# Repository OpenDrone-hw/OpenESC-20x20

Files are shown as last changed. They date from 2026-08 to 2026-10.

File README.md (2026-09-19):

# OpenESC-20x20

Open source 4-in-1 BLDC ESC with a 20 x 20 mm mounting pattern, part of the
incutec OpenDrone line. Four independent motor controllers, each with its own
MCU, gate driver and six MOSFETs, running AM32 and taking DShot over the
standard 8-pin connector.

<p>
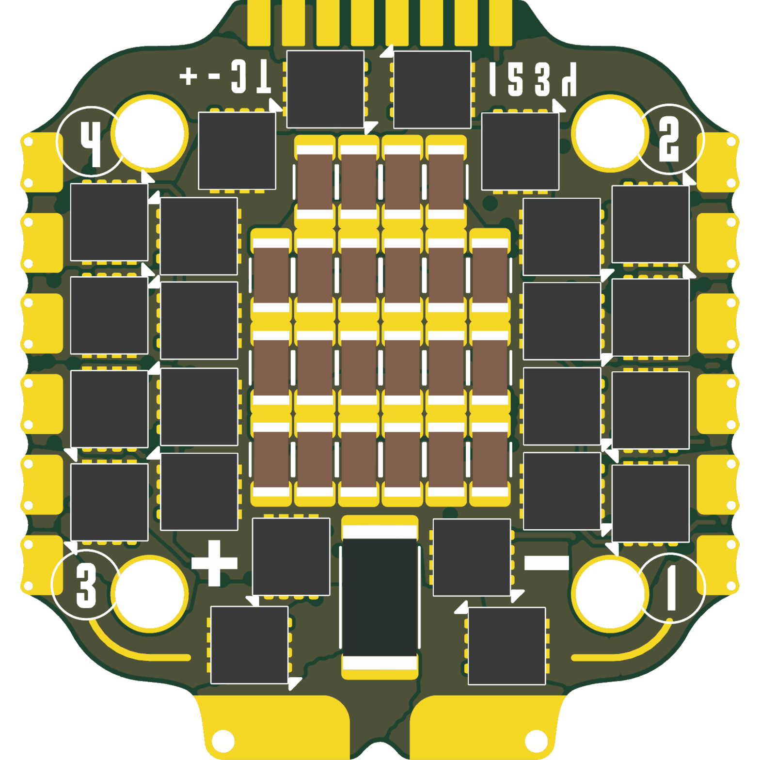
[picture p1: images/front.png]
OpenESC-20x20 top

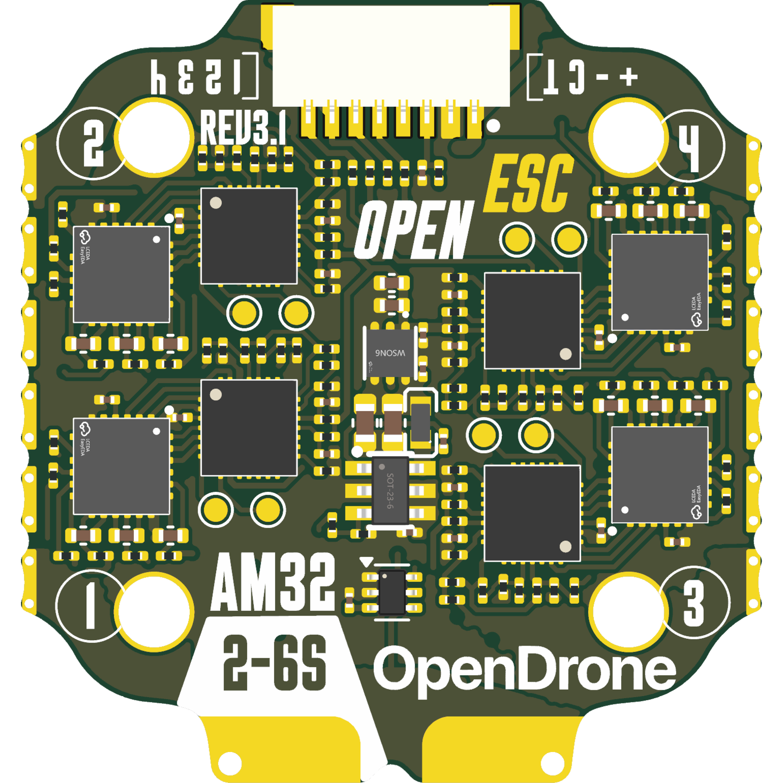
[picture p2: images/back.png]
OpenESC-20x20 bottom

</p>







## Specifications

| | |
|---|---|
| Continuous | 40 A / channel |
| Firmware | AM32 |
| ESC protocol | DShot, bidirectional |
| Telemetry | Extended DShot |
| Input | 2-6S LiPo (6.0-25.2 V) |
| BEC | None |
| MCU | One per motor |
| MOSFETs | 6 per motor |
| Current sense | On-board, 165 A |
| FC connector | JST-SH 8-pin |
| Mounting | 20 x 20 mm, 3.0 mm holes |
| Dimensions | 31.2 x 33.0 mm |
| PCB | 6-layer, 1.6 mm, 2 oz copper |

Technical write-up, part list and layout constraints: [AGENTS.md](AGENTS.md).

## In the line

What pairs with what, and what is available:
[opendrone.be](https://opendrone.be).

## Contributing

See [CONTRIBUTING.md](CONTRIBUTING.md).

## License

Hardware licensed under [CERN-OHL-S-2.0](https://ohwr.org/cern_ohl_s_v2.txt),
see [LICENSE](LICENSE).

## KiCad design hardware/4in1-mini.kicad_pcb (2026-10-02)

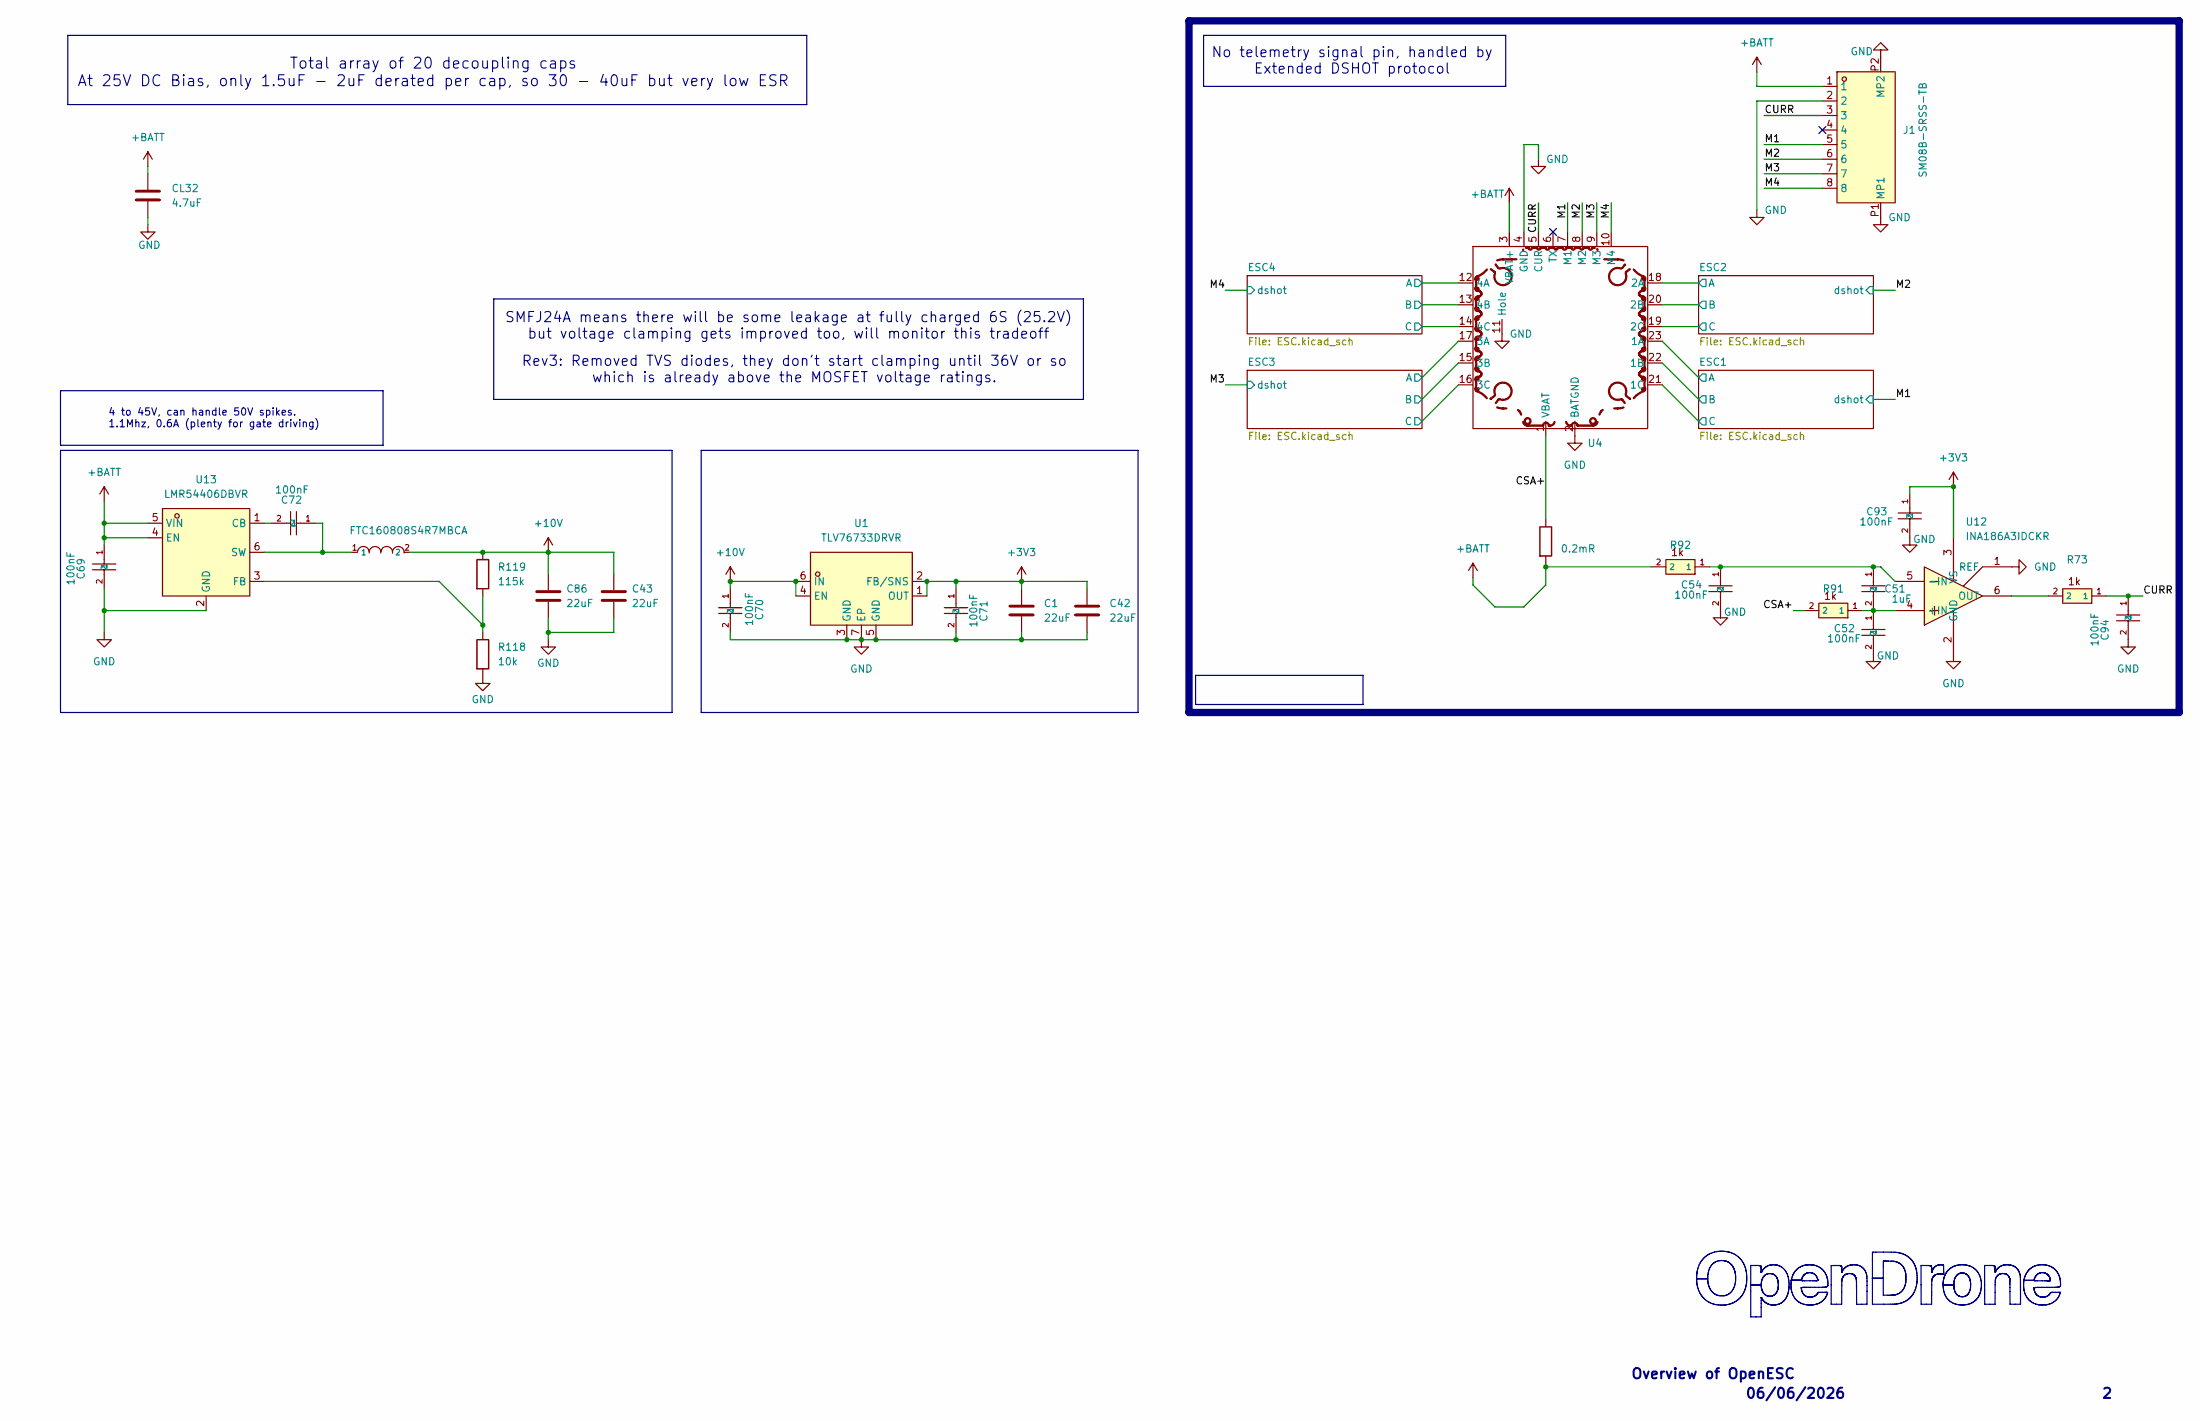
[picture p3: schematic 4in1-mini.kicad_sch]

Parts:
C1, C42: 22uF; C_0402_1005Metric; MPN CL05A226MQ5QUNC; LCSC C105226
C43, C86: 22uF; C_0603_1608Metric; MPN CL10A226MO7JZNC; LCSC C2762594
C51: 1uF; C_0402_1005Metric; MPN CC0402KRX7R6BB105; LCSC C7500381
C52, C54: 100nF; C_0402_WIDE; MPN CL05B104KB54PNC; LCSC C307331
C69, C70, C71, C72, C93, C94: 100nF; C_0201_0603Metric; MPN GRM033R6YA104KE14D; LCSC C181043
CL32: 4.7uF; C_1206_3216Metric; MPN TCC1206X7R475K500HT; LCSC C380366
J1: SM08B-SRSS-TB; JST_SM08B-SRSS-TB; MPN SM08B-SRSS-TB(LF)(SN); LCSC C160407
R73: 1k; R_0201_0603Metric; MPN 0201WMF1001TEE; LCSC C270365
R91, R92: 1k; C_0201_0603Metric; MPN 0201WMF1001TEE; LCSC C270365
R118: 10k; R_0201_0603Metric; MPN RC0201FR-0710KL; LCSC C106225
R119: 115k; R_0201_0603Metric; MPN RTT011153FTH; LCSC C166378
Rsense2: 0.2mR; R_2512_6332Metric; MPN ASR-S-3-0.2F; LCSC C695806
U1: TLV76733DRVR; WSON-6_L2.0-W2.0-P0.65-TL-EP; MPN TLV76733DRVR; LCSC C2848334
U4: 4in1ESC
U5: FTC160808S4R7MBCA; IND-SMD_L1.6-W0.8_FTC160865SR47MBCA; MPN FTC160808S4R7MBCA; LCSC C46594347
U12: INA186A3IDCKR; SOT-363_SC-70-6; MPN INA186A3IDCKR; LCSC C2058245
U13: LMR54406DBVR; SOT-23-6_L2.9-W1.6-P0.95-LS2.8-BR; MPN LMR54406DBVR; LCSC C5219316

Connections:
+3V3: C1.2, C42.2, C71.1, C93.1, U1.1 (OUT), U1.2 (FB/SNS), U12.3 (VS); also elsewhere on the board
+10V: C43.1, C70.1, C86.1, R119.1, U1.4 (EN), U1.6 (IN), U5.2; also elsewhere on the board
+BATT: C69.1, CL32.1, J1.1, R92.2, Rsense2.2, U4.3 (VBAT+), U13.4 (EN), U13.5 (VIN); also elsewhere on the board
/CSA+: R91.2, Rsense2.1, U4.1 (VBAT)
/CURR: C94.1, J1.3, R73.1, U4.5 (CUR)
/ESC1/MotorA: U4.23 (1A); also elsewhere on the board
/ESC1/MotorB: U4.22 (1B); also elsewhere on the board
/ESC1/MotorC: U4.21 (1C); also elsewhere on the board
/ESC2/MotorA: U4.18 (2A); also elsewhere on the board
/ESC2/MotorB: U4.20 (2B); also elsewhere on the board
/ESC2/MotorC: U4.19 (2C); also elsewhere on the board
/ESC3/MotorA: U4.17 (3A); also elsewhere on the board
/ESC3/MotorB: U4.15 (3B); also elsewhere on the board
/ESC3/MotorC: U4.16 (3C); also elsewhere on the board
/ESC4/MotorA: U4.12 (4A); also elsewhere on the board
/ESC4/MotorB: U4.13 (4B); also elsewhere on the board
/ESC4/MotorC: U4.14 (4C); also elsewhere on the board
/M1: J1.5, U4.7 (M1); also elsewhere on the board
/M2: J1.6, U4.8 (M2); also elsewhere on the board
/M3: J1.7, U4.9 (M3); also elsewhere on the board
/M4: J1.8, U4.10 (M4); also elsewhere on the board
GND: C1.1, C42.1, C43.2, C52.2, C54.2, C69.2, C70.2, C71.2, C86.2, C93.2, C94.2, CL32.2, J1.2, J1.P1 (MP1), J1.P2 (MP2), R118.2, U1.3 (GND), U1.5 (GND), U1.7 (EP), U4.2 (BATGND), U4.4 (GND), U4.11 (Hole), U12.1 (REF), U12.2 (GND), U13.2 (GND); also elsewhere on the board
unnamed: C51.2, C52.1, R91.1, U12.4 (+IN)
unnamed: C51.1, C54.1, R92.1, U12.5 (-IN)
unnamed: R73.2, U12.6 (OUT)
unnamed: C72.2, U13.1 (CB)
unnamed: R118.1, R119.2, U13.3 (FB)
unnamed: C72.1, U5.1, U13.6 (SW)

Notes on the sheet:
06/06/2026
No telemetry signal pin, handled by Extended DSHOT protocol
4 to 45V, can handle 50V spikes. 1.1Mhz, 0.6A (plenty for gate driving)
Rev3: Removed TVS diodes, they don't start clamping until 36V or so which is already above the MOSFET voltage ratings.
SMFJ24A means there will be some leakage at fully charged 6S (25.2V) but voltage clamping gets improved too, will monitor this tradeoff
Overview of OpenESC
Total array of 20 decoupling caps At 25V DC Bias, only 1.5uF - 2uF derated per cap, so 30 - 40uF but very low ESR

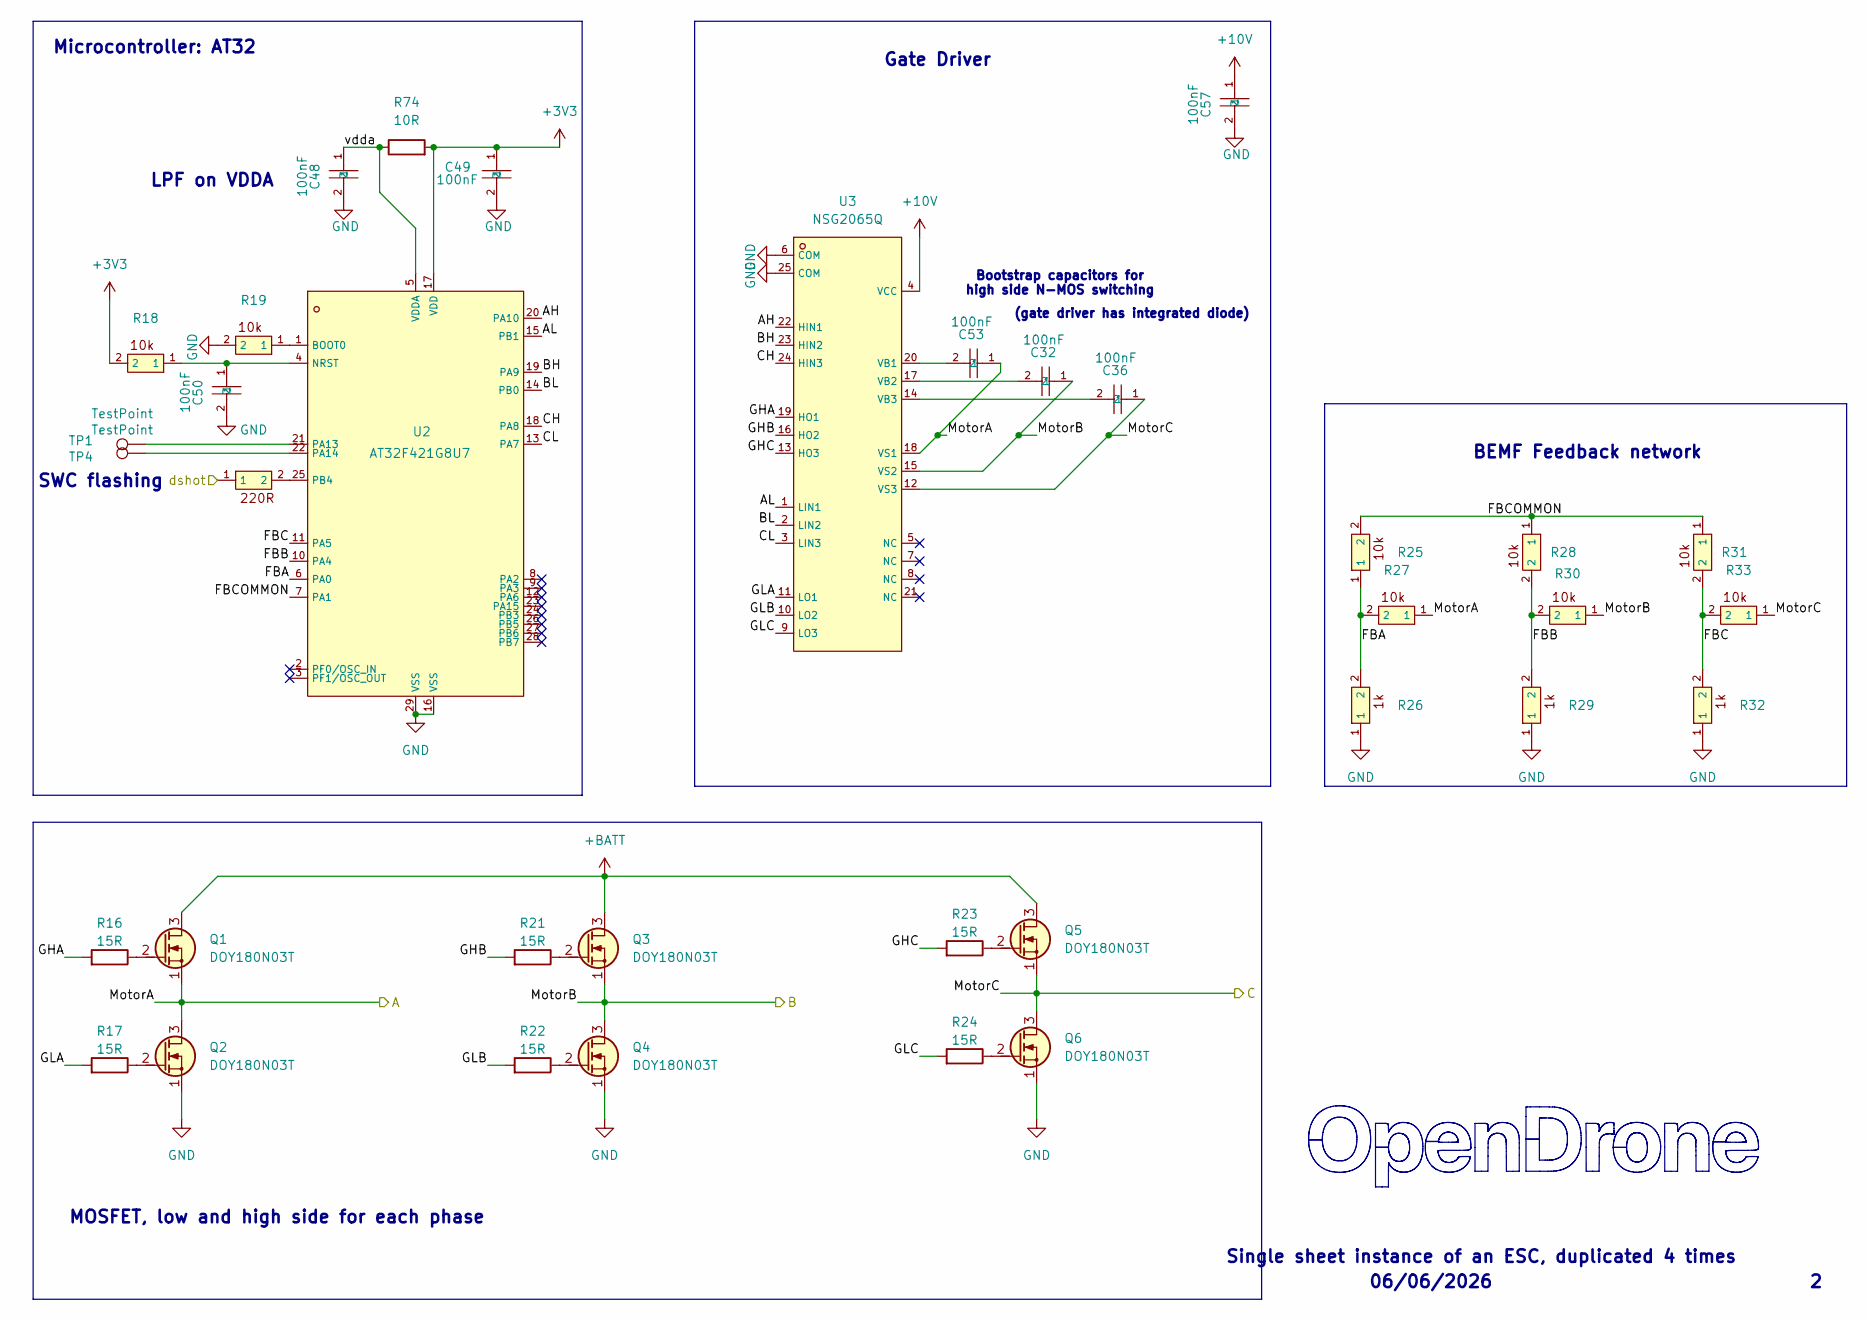
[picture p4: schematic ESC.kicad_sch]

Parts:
C32, C36, C53: 100nF; C_0402_WIDE; MPN CL05B104KB54PNC; LCSC C307331
C48, C49, C50, C57: 100nF; C_0201_0603Metric; MPN GRM033R6YA104KE14D; LCSC C181043
Q1, Q2, Q3, Q4, Q5, Q6: DOY180N03T; Diodes_PowerDI3333-8; MPN DOY180N03T; LCSC C49441966
R16, R17, R21, R22, R23, R24: 15R; R_0201_0603Metric; MPN 0201WMF150JTEE; LCSC C473542
R18, R19, R25, R27, R28, R30, R31, R33: 10k; R_0201_0603Metric; MPN RC0201FR-0710KL; LCSC C106225
R20: 220R; R_0201_0603Metric; MPN AC0201FR-07220RL; LCSC C226468
R26, R29, R32: 1k; R_0201_0603Metric; MPN 0201WMF1001TEE; LCSC C270365
R74: 10R; R_0201_0603Metric; MPN RC0201FR-0710RL; LCSC C106226
TP1, TP4: TestPoint; TestPoint_Pad_D1.0mm
U2: AT32F421G8U7; QFN-28_L4.0-W4.0-P0.40-TL-EP2.4; MPN AT32F421G8U7; LCSC C2765098
U3: NSG2065Q; QFN-24_L4.0-W4.0-P0.50-TL-EP2.8; MPN NSG2065Q; LCSC C41414478

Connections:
+3V3: C49.1, R18.2, R74.2, U2.17 (VDD); also elsewhere on the board
+10V: C57.1, U3.4 (VCC); also elsewhere on the board
+BATT: Q1.3 (D), Q3.3 (D), Q5.3 (D); also elsewhere on the board
/ESC1/AH: U2.20 (PA10), U3.22 (HIN1)
/ESC1/AL: U2.15 (PB1), U3.1 (LIN1)
/ESC1/BH: U2.19 (PA9), U3.23 (HIN2)
/ESC1/BL: U2.14 (PB0), U3.2 (LIN2)
/ESC1/CH: U2.18 (PA8), U3.24 (HIN3)
/ESC1/CL: U2.13 (PA7), U3.3 (LIN3)
/ESC1/FBA: R25.1, R26.2, R27.2, U2.6 (PA0)
/ESC1/FBB: R28.2, R29.2, R30.2, U2.10 (PA4)
/ESC1/FBC: R31.2, R32.2, R33.2, U2.11 (PA5)
/ESC1/FBCOMMON: R25.2, R28.1, R31.1, U2.7 (PA1)
/ESC1/GHA: R16.1, U3.19 (HO1)
/ESC1/GHB: R21.1, U3.16 (HO2)
/ESC1/GHC: R23.1, U3.13 (HO3)
/ESC1/GLA: R17.1, U3.11 (LO1)
/ESC1/GLB: R22.1, U3.10 (LO2)
/ESC1/GLC: R24.1, U3.9 (LO3)
/ESC1/MotorA: C53.1, Q1.1 (S), Q2.3 (D), R27.1, U3.18 (VS1); also elsewhere on the board
/ESC1/MotorB: C32.1, Q3.1 (S), Q4.3 (D), R30.1, U3.15 (VS2); also elsewhere on the board
/ESC1/MotorC: C36.1, Q5.1 (S), Q6.3 (D), R33.1, U3.12 (VS3); also elsewhere on the board
/ESC1/vdda: C48.1, R74.1, U2.5 (VDDA)
/M1: R20.1; also elsewhere on the board
GND: C48.2, C49.2, C50.2, C57.2, Q2.1 (S), Q4.1 (S), Q6.1 (S), R19.2, R26.1, R29.1, R32.1, U2.16 (VSS), U2.29 (VSS), U3.6 (COM), U3.25 (COM); also elsewhere on the board
unnamed: Q1.2 (G), R16.2
unnamed: Q2.2 (G), R17.2
unnamed: Q3.2 (G), R21.2
unnamed: Q4.2 (G), R22.2
unnamed: Q5.2 (G), R23.2
unnamed: Q6.2 (G), R24.2
unnamed: R19.1, U2.1 (BOOT0)
unnamed: C50.1, R18.1, U2.4 (NRST)
unnamed: TP1.1 (1_1), U2.21 (PA13)
unnamed: TP4.1 (1_1), U2.22 (PA14)
unnamed: R20.2, U2.25 (PB4)
unnamed: C53.2, U3.20 (VB1)
unnamed: C32.2, U3.17 (VB2)
unnamed: C36.2, U3.14 (VB3)

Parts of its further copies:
C33, C34, C35, C37, C38, C39, C59, C73, C83: 100nF; C_0402_WIDE; MPN CL05B104KB54PNC; LCSC C307331
C44, C45, C46, C63, C64, C65, C66, C77, C78, C79, C80, C88: 100nF; C_0201_0603Metric; MPN GRM033R6YA104KE14D; LCSC C181043
Q7, Q8, Q9, Q10, Q11, Q12, Q13, Q14, Q15, Q16, Q17, Q18, Q19, Q20, Q21, Q22, Q23, Q24: DOY180N03T; Diodes_PowerDI3333-8; MPN DOY180N03T; LCSC C49441966
R1, R2, R6, R7, R8, R9, R37, R38, R42, R43, R44, R45, R55, R56, R60, R61, R62, R63: 15R; R_0201_0603Metric; MPN 0201WMF150JTEE; LCSC C473542
R3, R4, R10, R12, R13, R15, R34, R36, R39, R40, R46, R48, R49, R51, R52, R54, R57, R58, R64, R66, R67, R69, R70, R72: 10k; R_0201_0603Metric; MPN RC0201FR-0710KL; LCSC C106225
R5, R41, R59: 220R; R_0201_0603Metric; MPN AC0201FR-07220RL; LCSC C226468
R11, R14, R35, R47, R50, R53, R65, R68, R71: 1k; R_0201_0603Metric; MPN 0201WMF1001TEE; LCSC C270365
R75, R76, R77: 10R; R_0201_0603Metric; MPN RC0201FR-0710RL; LCSC C106226
TP2, TP3, TP5, TP6, TP7, TP8: TestPoint; TestPoint_Pad_D1.0mm
U6, U8, U10: AT32F421G8U7; QFN-28_L4.0-W4.0-P0.40-TL-EP2.4; MPN AT32F421G8U7; LCSC C2765098
U7, U9, U11: NSG2065Q; QFN-24_L4.0-W4.0-P0.50-TL-EP2.8; MPN NSG2065Q; LCSC C41414478

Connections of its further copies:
+3V3: C45.1, C65.1, C79.1, R3.2, R39.2, R57.2, R75.2, R76.2, R77.2, U6.17 (VDD), U8.17 (VDD), U10.17 (VDD); also elsewhere on the board
+10V: C63.1, C77.1, C88.1, U7.4 (VCC), U9.4 (VCC), U11.4 (VCC); also elsewhere on the board
+BATT: Q7.3 (D), Q9.3 (D), Q11.3 (D), Q13.3 (D), Q15.3 (D), Q17.3 (D), Q19.3 (D), Q21.3 (D), Q23.3 (D); also elsewhere on the board
/ESC2/AH: U6.20 (PA10), U7.22 (HIN1)
/ESC2/AL: U6.15 (PB1), U7.1 (LIN1)
/ESC2/BH: U6.19 (PA9), U7.23 (HIN2)
/ESC2/BL: U6.14 (PB0), U7.2 (LIN2)
/ESC2/CH: U6.18 (PA8), U7.24 (HIN3)
/ESC2/CL: U6.13 (PA7), U7.3 (LIN3)
/ESC2/FBA: R10.1, R11.2, R12.2, U6.6 (PA0)
/ESC2/FBB: R13.2, R14.2, R15.2, U6.10 (PA4)
/ESC2/FBC: R34.2, R35.2, R36.2, U6.11 (PA5)
/ESC2/FBCOMMON: R10.2, R13.1, R34.1, U6.7 (PA1)
/ESC2/GHA: R1.1, U7.19 (HO1)
/ESC2/GHB: R6.1, U7.16 (HO2)
/ESC2/GHC: R8.1, U7.13 (HO3)
/ESC2/GLA: R2.1, U7.11 (LO1)
/ESC2/GLB: R7.1, U7.10 (LO2)
/ESC2/GLC: R9.1, U7.9 (LO3)
/ESC2/MotorA: C59.1, Q7.1 (S), Q8.3 (D), R12.1, U7.18 (VS1); also elsewhere on the board
/ESC2/MotorB: C33.1, Q9.1 (S), Q10.3 (D), R15.1, U7.15 (VS2); also elsewhere on the board
/ESC2/MotorC: C37.1, Q11.1 (S), Q12.3 (D), R36.1, U7.12 (VS3); also elsewhere on the board
/ESC2/vdda: C44.1, R75.1, U6.5 (VDDA)
/ESC3/AH: U8.20 (PA10), U9.22 (HIN1)
/ESC3/AL: U8.15 (PB1), U9.1 (LIN1)
/ESC3/BH: U8.19 (PA9), U9.23 (HIN2)
/ESC3/BL: U8.14 (PB0), U9.2 (LIN2)
/ESC3/CH: U8.18 (PA8), U9.24 (HIN3)
/ESC3/CL: U8.13 (PA7), U9.3 (LIN3)
/ESC3/FBA: R46.1, R47.2, R48.2, U8.6 (PA0)
/ESC3/FBB: R49.2, R50.2, R51.2, U8.10 (PA4)
/ESC3/FBC: R52.2, R53.2, R54.2, U8.11 (PA5)
/ESC3/FBCOMMON: R46.2, R49.1, R52.1, U8.7 (PA1)
/ESC3/GHA: R37.1, U9.19 (HO1)
/ESC3/GHB: R42.1, U9.16 (HO2)
/ESC3/GHC: R44.1, U9.13 (HO3)
/ESC3/GLA: R38.1, U9.11 (LO1)
/ESC3/GLB: R43.1, U9.10 (LO2)
/ESC3/GLC: R45.1, U9.9 (LO3)
/ESC3/MotorA: C73.1, Q13.1 (S), Q14.3 (D), R48.1, U9.18 (VS1); also elsewhere on the board
/ESC3/MotorB: C34.1, Q15.1 (S), Q16.3 (D), R51.1, U9.15 (VS2); also elsewhere on the board
/ESC3/MotorC: C38.1, Q17.1 (S), Q18.3 (D), R54.1, U9.12 (VS3); also elsewhere on the board
/ESC3/vdda: C64.1, R76.1, U8.5 (VDDA)
/ESC4/AH: U10.20 (PA10), U11.22 (HIN1)
/ESC4/AL: U10.15 (PB1), U11.1 (LIN1)
/ESC4/BH: U10.19 (PA9), U11.23 (HIN2)
/ESC4/BL: U10.14 (PB0), U11.2 (LIN2)
/ESC4/CH: U10.18 (PA8), U11.24 (HIN3)
/ESC4/CL: U10.13 (PA7), U11.3 (LIN3)
/ESC4/FBA: R64.1, R65.2, R66.2, U10.6 (PA0)
/ESC4/FBB: R67.2, R68.2, R69.2, U10.10 (PA4)
/ESC4/FBC: R70.2, R71.2, R72.2, U10.11 (PA5)
/ESC4/FBCOMMON: R64.2, R67.1, R70.1, U10.7 (PA1)
/ESC4/GHA: R55.1, U11.19 (HO1)
/ESC4/GHB: R60.1, U11.16 (HO2)
/ESC4/GHC: R62.1, U11.13 (HO3)
/ESC4/GLA: R56.1, U11.11 (LO1)
/ESC4/GLB: R61.1, U11.10 (LO2)
/ESC4/GLC: R63.1, U11.9 (LO3)
/ESC4/MotorA: C83.1, Q19.1 (S), Q20.3 (D), R66.1, U11.18 (VS1); also elsewhere on the board
/ESC4/MotorB: C35.1, Q21.1 (S), Q22.3 (D), R69.1, U11.15 (VS2); also elsewhere on the board
/ESC4/MotorC: C39.1, Q23.1 (S), Q24.3 (D), R72.1, U11.12 (VS3); also elsewhere on the board
/ESC4/vdda: C78.1, R77.1, U10.5 (VDDA)
/M2: R5.1; also elsewhere on the board
/M3: R41.1; also elsewhere on the board
/M4: R59.1; also elsewhere on the board
GND: C44.2, C45.2, C46.2, C63.2, C64.2, C65.2, C66.2, C77.2, C78.2, C79.2, C80.2, C88.2, Q8.1 (S), Q10.1 (S), Q12.1 (S), Q14.1 (S), Q16.1 (S), Q18.1 (S), Q20.1 (S), Q22.1 (S), Q24.1 (S), R4.2, R11.1, R14.1, R35.1, R40.2, R47.1, R50.1, R53.1, R58.2, R65.1, R68.1, R71.1, U6.16 (VSS), U6.29 (VSS), U7.6 (COM), U7.25 (COM), U8.16 (VSS), U8.29 (VSS), U9.6 (COM), U9.25 (COM), U10.16 (VSS), U10.29 (VSS), U11.6 (COM), U11.25 (COM); also elsewhere on the board
unnamed: Q7.2 (G), R1.2
unnamed: Q8.2 (G), R2.2
unnamed: Q9.2 (G), R6.2
unnamed: Q10.2 (G), R7.2
unnamed: Q11.2 (G), R8.2
unnamed: Q12.2 (G), R9.2
unnamed: Q13.2 (G), R37.2
unnamed: Q14.2 (G), R38.2
unnamed: Q15.2 (G), R42.2
unnamed: Q16.2 (G), R43.2
unnamed: Q17.2 (G), R44.2
unnamed: Q18.2 (G), R45.2
unnamed: Q19.2 (G), R55.2
unnamed: Q20.2 (G), R56.2
unnamed: Q21.2 (G), R60.2
unnamed: Q22.2 (G), R61.2
unnamed: Q23.2 (G), R62.2
unnamed: Q24.2 (G), R63.2
unnamed: R4.1, U6.1 (BOOT0)
unnamed: C46.1, R3.1, U6.4 (NRST)
unnamed: TP2.1 (1_1), U6.21 (PA13)
unnamed: TP3.1 (1_1), U6.22 (PA14)
unnamed: R5.2, U6.25 (PB4)
unnamed: C59.2, U7.20 (VB1)
unnamed: C33.2, U7.17 (VB2)
unnamed: C37.2, U7.14 (VB3)
unnamed: R40.1, U8.1 (BOOT0)
unnamed: C66.1, R39.1, U8.4 (NRST)
unnamed: TP5.1 (1_1), U8.21 (PA13)
unnamed: TP6.1 (1_1), U8.22 (PA14)
unnamed: R41.2, U8.25 (PB4)
unnamed: C73.2, U9.20 (VB1)
unnamed: C34.2, U9.17 (VB2)
unnamed: C38.2, U9.14 (VB3)
unnamed: R58.1, U10.1 (BOOT0)
unnamed: C80.1, R57.1, U10.4 (NRST)
unnamed: TP7.1 (1_1), U10.21 (PA13)
unnamed: TP8.1 (1_1), U10.22 (PA14)
unnamed: R59.2, U10.25 (PB4)
unnamed: C83.2, U11.20 (VB1)
unnamed: C35.2, U11.17 (VB2)
unnamed: C39.2, U11.14 (VB3)

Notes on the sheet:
Bootstrap capacitors for high side N-MOS switching
Gate Driver
MOSFET, low and high side for each phase
Single sheet instance of an ESC, duplicated 4 times
Microcontroller: AT32
SWC flashing
(gate driver has integrated diode)
06/06/2026
BEMF Feedback network
LPF on VDDA

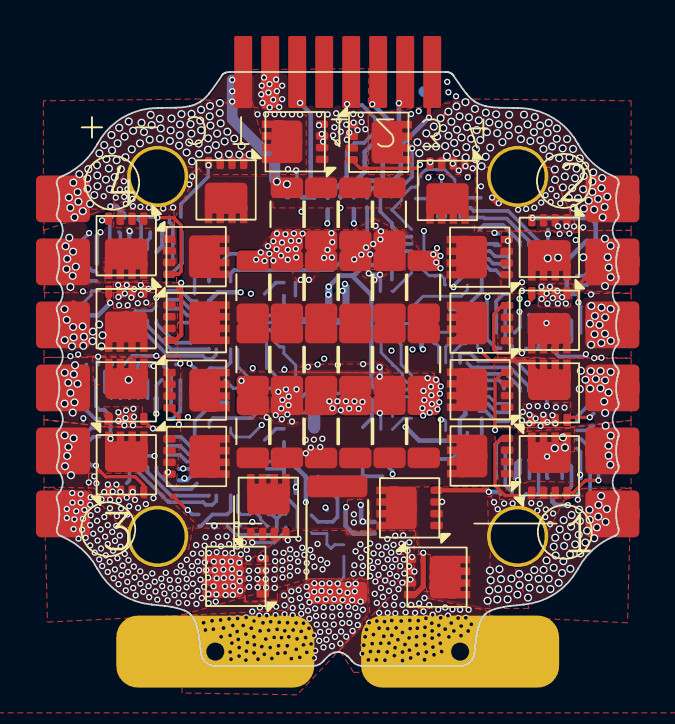
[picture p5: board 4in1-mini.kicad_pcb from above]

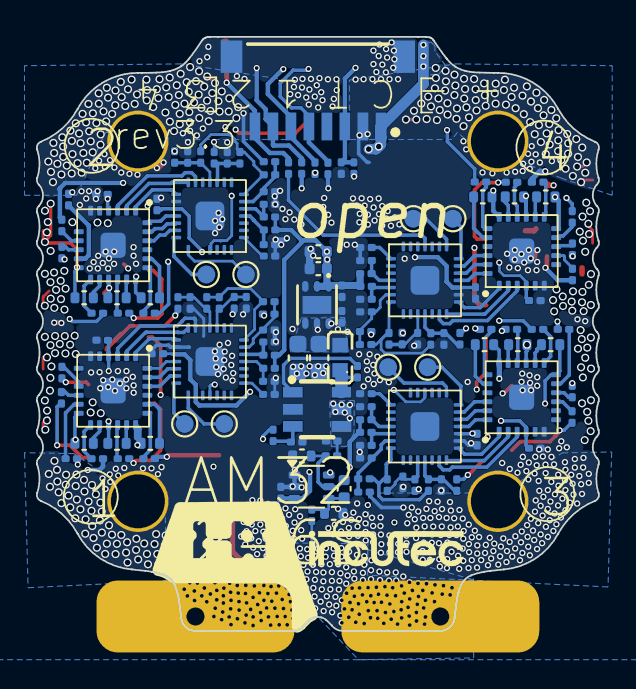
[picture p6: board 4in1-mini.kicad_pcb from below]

Board: 6 copper layers, 31.2 x 33.0 mm, 191 parts (143 on the bottom side), 152 nets.

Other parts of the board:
CL33, CL34, CL35, CL36, CL38, CL39, CL40, CL42, CL43, CL44, CL45, CL46, CL47, CL48, CL49, CL50, CL50#2, CL51, CL51#2, CL54, CL55: 4.7uF; C_1206_3216Metric

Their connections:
+BATT: CL33.1, CL34.1, CL35.1, CL36.1, CL38.1, CL39.1, CL40.1, CL42.1, CL43.1, CL44.1, CL45.1, CL46.1, CL47.1, CL48.1, CL49.1, CL50.1, CL50#2.1, CL51.1, CL51#2.1, CL54.1, CL55.1; also elsewhere on the board
GND: CL33.2, CL34.2, CL35.2, CL36.2, CL38.2, CL39.2, CL40.2, CL42.2, CL43.2, CL44.2, CL45.2, CL46.2, CL47.2, CL48.2, CL49.2, CL50.2, CL50#2.2, CL51.2, CL51#2.2, CL54.2, CL55.2; also elsewhere on the board

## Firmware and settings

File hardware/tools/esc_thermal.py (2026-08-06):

#!/usr/bin/env python3
"""
4in1 ESC Power Loss & Thermal Calculator

Models AM32 trapezoidal 6-step commutation with steady-state and transient thermal.

MOSFET profiles:
  20x20: SP40N03GNJ (Siliup Ver-1.2), Rg=15Ω. SUPERSEDED POWER STAGE. The
         shipping OpenESC-20x20 uses 24x DOY180N03T (30 V, PowerDI3333-8, LCSC
         C49441966, see hardware/docs/DESIGN.md). This profile has not been
         re-parameterized from the DOY180N03T datasheet, so its loss and
         temperature numbers do not describe the current board. Board geometry
         (1030 mm², 6 layers) is current.
  30x30: SP40N01GHNK (Siliup Ver-1.1), Rg=8Ω. Matches the OpenESC-30x30 board.
  Gate driver for both: NSG2065Q (NSIC V1.0).
"""

import argparse
import math

# ═══════════════════════════════════════════════════════════════
#  MOSFET profiles: all values from datasheets
# ═══════════════════════════════════════════════════════════════

PROFILES = {
    "20x20": {
        "name":         "20×20  SP40N03GNJ (3×3mm, SUPERSEDED, not the shipping part)",
        # ── SP40N03GNJ datasheet (Ver-1.2) ──
        "rds_on":       2.9e-3,     # Ω typ @ Vgs=10V, ID=20A, 25°C
        "rds_on_max":   3.7e-3,     # Ω max
        "rds_tempco":   1.45,       # normalized @ 100°C (p3 curve)
        "rds_tempco_150": 1.70,     # normalized @ 150°C
        "qg_at_10v":    15e-9,      # C  (from gate charge curve p3 @ Vgs=10V)
        "qgd":          5.5e-9,     # C  gate-drain (Miller) charge
        "vgs":          10.0,       # V
        "rg":           15.0,       # Ω  external gate resistor
        "v_plateau":    3.0,        # V  Miller plateau (transfer curve p3)
        # Switching: Qgd / I_gate through Rg
        #   I_on  = (10-3)/15 = 0.47A → tr = 5.5nC/0.47A = 11.7ns
        #   I_off = 3/15      = 0.20A → tf = 5.5nC/0.20A = 27.5ns
        "tr":           11.7e-9,
        "tf":           27.5e-9,
        "vf_body_cold": 0.80,       # V  @ ~30A, 25°C (p4 curve extrapolated)
        "vf_body_hot":  0.65,       # V  @ ~30A, 100°C
        "trr":          14e-9,      # s  (p2)
        "qrr":          23e-9,      # C  (p2)
        "rth_jc":       2.27,       # °C/W (p2)
        "pd_max":       55.0,       # W
        "tj_max":       150.0,      # °C
        # Board
        "board_mm":     20,         # mm mounting pattern
        "board_area":   1030.0,     # mm² actual PCB (~31×33mm, from Edge.Cuts)
        "r_copper":     3.2e-3,     # Ω per phase trace
        "r_shunt":      0.2e-3,     # Ω
        "layers":       6,
        "oz_outer":     1,          # oz copper
        "oz_inner":     0.5,
    },
    "30x30": {
        "name":         "30×30  SP40N01GHNK (5×6mm)",
        # ── SP40N01GHNK datasheet (Ver-1.1) ──
        "rds_on":       1.2e-3,     # Ω typ @ Vgs=10V, ID=20A, 25°C
        "rds_on_max":   1.5e-3,     # Ω max
        "rds_tempco":   1.45,       # normalized @ 100°C (p3 curve)
        "rds_tempco_150": 1.70,     # normalized @ 150°C
        "qg_at_10v":    65e-9,      # C  (from gate charge curve p3 @ Vgs=10V)
        "qgd":          15.5e-9,    # C  gate-drain (Miller) charge
        "vgs":          10.0,       # V
        "rg":           8.0,        # Ω  external gate resistor
        "v_plateau":    3.5,        # V  Miller plateau (transfer curve p3, higher Vth)
        # Switching: Qgd / I_gate through Rg
        #   I_on  = (10-3.5)/8 = 0.81A → tr = 15.5nC/0.81A = 19.1ns
        #   I_off = 3.5/8      = 0.44A → tf = 15.5nC/0.44A = 35.2ns
        "tr":           19.1e-9,
        "tf":           35.2e-9,
        "vf_body_cold": 0.75,       # V  @ ~30A, 25°C (p3 source-drain diode curve)
        "vf_body_hot":  0.60,       # V  @ ~30A, 100°C
        "trr":          29e-9,      # s  (p2)
        "qrr":          113e-9,     # C  (p2), much higher than SP40N03GNJ
        "rth_jc":       0.96,       # °C/W (p2), better, larger package
        "pd_max":       130.0,      # W
        "tj_max":       150.0,      # °C
        # Board
        "board_mm":     30,         # mm mounting pattern
        "board_area":   1770.0,     # mm² actual PCB (~42×43mm, from Edge.Cuts)
        "r_copper":     2.0e-3,     # Ω per phase (wider traces, more area)
        "r_shunt":      0.2e-3,     # Ω
        "layers":       6,
        "oz_outer":     1,
        "oz_inner":     0.5,
    },
}

# ─── NSG2065Q gate driver (shared) ───
GATE_DRIVER = {
    "dead_time_typ":  200e-9,   # s  hardware dead time (100-300ns, p6)
    "dead_time_min":  100e-9,
    "dead_time_max":  300e-9,
    "io_source":      1.2,      # A
    "io_sink":        1.5,      # A
}

# ─── Thermal scenarios ───
# h = convective heat transfer coefficient (W/m²·K)
# θ_board = 1 / (h × A_both_sides)
THERMAL_SCENARIOS = {
    "still":        {"h": 15,   "label": "Still air (bench)"},
    "light_flow":   {"h": 50,   "label": "Light prop wash (~3m/s)"},
    "strong_flow":  {"h": 100,  "label": "Strong prop wash (~8m/s)"},
    "direct_blast": {"h": 150,  "label": "Direct motor blast (>10m/s)"},
}

# ─── PCB stackup options for thermal comparison ───
# Copper thickness: 1oz=35µm, 2oz=70µm, 0.5oz=17.5µm
# Thermal conductivity: Cu=385 W/(m·K), FR4=0.3 W/(m·K)
PCB_OPTIONS = {
    "jlcpcb_6L_1oz": {
        "label":    "JLCPCB 6L 1oz/0.5oz (current)",
        "oz_outer": 1.0, "oz_inner": 0.5, "layers": 6,
        "notes":    "Standard, free POFV via-in-pad",
    },
    "jlcpcb_6L_2oz": {
        "label":    "JLCPCB 6L 2oz/2oz (max multilayer)",
        "oz_outer": 2.0, "oz_inner": 2.0, "layers": 6,
        "notes":    "Max Cu at JLCPCB for 6L, ~2x bare board cost",
    },
    "jlcpcb_4L_2oz": {
        "label":    "JLCPCB 4L 2oz/2oz",
        "oz_outer": 2.0, "oz_inner": 2.0, "layers": 4,
        "notes":    "Cheaper than 6L, no free POFV",
    },
    "jlcpcb_6L_3oz": {
        "label":    "JLCPCB 6L 3oz/1oz (industry std ESC)",
        "oz_outer": 3.0, "oz_inner": 1.0, "layers": 6,
        "notes":    "What commercial 35A ESCs use",
    },
    "pcbway_6L_4oz": {
        "label":    "PCBWay 6L 4oz/2oz (heavy Cu)",
        "oz_outer": 4.0, "oz_inner": 2.0, "layers": 6,
        "notes":    "PCBWay supports >2oz on multilayer, premium cost",
    },
}


def board_theta(area_mm2: float, h: float) -> float:
    """Board-to-ambient thermal resistance (°C/W), both sides convecting."""
    area_m2 = area_mm2 * 2.0 * 1e-6
    return 1.0 / (h * area_m2)


def board_thermal_mass(area_mm2: float, layers: int, oz_outer: float, oz_inner: float,
                       board_thickness_mm: float = 1.6) -> float:
    """Board thermal capacitance in J/K.

    Accounts for FR-4 substrate and copper layers.
    FR-4: ρ=1.85 g/cm³, cp=1.1 J/(g·K)
    Cu:   ρ=8.96 g/cm³, cp=0.385 J/(g·K)
    """
    area_cm2 = area_mm2 * 1e-2  # mm² → cm²

    # FR-4 volume (approximate: total thickness minus copper)
    cu_outer_mm = oz_outer * 0.035  # mm per oz
    cu_inner_mm = oz_inner * 0.035 if oz_inner else 0.0175
    n_inner = max(layers - 2, 0)
    total_cu_mm = 2 * cu_outer_mm + n_inner * cu_inner_mm
    fr4_mm = board_thickness_mm - total_cu_mm
    fr4_vol_cm3 = area_cm2 * fr4_mm * 0.1  # cm²×mm→cm³ needs ×0.1
    fr4_mass = fr4_vol_cm3 * 1.85
    fr4_cth = fr4_mass * 1.1

    # Copper volume
    cu_vol_cm3 = area_cm2 * total_cu_mm * 0.1
    cu_mass = cu_vol_cm3 * 8.96
    cu_cth = cu_mass * 0.385

    return fr4_cth + cu_cth


def copper_resistance_scaled(r_base: float, oz_base: float, oz_new: float) -> float:
    """Scale copper trace resistance for different copper weight.
    R ∝ 1/thickness, so doubling oz halves resistance.
    """
    return r_base * oz_base / oz_new


def calc_phase_losses(i: float, v_bus: float, duty: float, f_pwm: float,
                      comp_pwm: bool, dead_time: float, p: dict,
                      r_copper_override: float = None) -> dict:
    """Calculate losses for one active phase pair."""
    rds = p["rds_on"] * p["rds_tempco"]  # hot Rds(on)
    vf = p["vf_body_hot"]
    r_cu = r_copper_override if r_copper_override else p["r_copper"]

    # Conduction
    p_cond_hs = i**2 * rds * duty
    if comp_pwm:
        p_cond_ls = i**2 * rds * (1.0 - duty)
        p_body = 0.0
    else:
        p_cond_ls = 0.0
        p_body = vf * i * (1.0 - duty)
    p_cond_low = i**2 * rds  # LOW-phase FET, 100% on

    # Switching (Miller plateau crossing)
    p_switch = 0.5 * v_bus * i * (p["tr"] + p["tf"]) * f_pwm

    # Dead time (both edges per PWM cycle)
    p_dead = vf * i * dead_time * 2.0 * f_pwm

    # Reverse recovery (Qrr-based model)
    p_rr = p["qrr"] * v_bus * f_pwm

    # Gate drive (HS at f_pwm, LS at commutation freq ~200Hz)
    p_gate = p["qg_at_10v"] * p["vgs"] * f_pwm + p["qg_at_10v"] * p["vgs"] * 200

    # Copper (both phase traces in the current path)
    p_copper = i**2 * r_cu * 2.0

    # Shunt
    p_shunt = i**2 * p["r_shunt"]

    p_fet = p_cond_hs + p_cond_ls + p_body + p_cond_low + p_switch + p_dead + p_rr + p_gate
    p_passive = p_copper + p_shunt
    p_total = p_fet + p_passive

    return {
        "p_cond_hs": p_cond_hs, "p_cond_ls": p_cond_ls, "p_body": p_body,
        "p_cond_low": p_cond_low, "p_switch": p_switch, "p_dead": p_dead,
        "p_rr": p_rr, "p_gate": p_gate, "p_copper": p_copper, "p_shunt": p_shunt,
        "p_fet": p_fet, "p_passive": p_passive, "p_total": p_total,
    }


def transient_time_to_tj(p_board: float, theta_ba: float, c_th: float,
                         tj_max: float, t_ambient: float) -> float:
    """Time (seconds) from ambient to Tj_max under constant power.

    Simple first-order RC model: ΔT(t) = ΔT_ss × (1 - e^(-t/τ))
    τ = C_th × θ_ba
    Returns float('inf') if steady-state ΔT < (Tj_max - T_ambient).
    """
    dt_max = tj_max - t_ambient
    dt_ss = p_board * theta_ba
    if dt_ss <= dt_max:
        return float('inf')  # never reaches Tj_max
    tau = c_th * theta_ba
    return -tau * math.log(1.0 - dt_max / dt_ss)


def print_full_report(profile_key: str, i: float, v_bus: float, duty: float,
                      f_pwm: float, comp_pwm: bool, dead_time: float, n_active: int):
    p = PROFILES[profile_key]
    rds_hot = p["rds_on"] * p["rds_tempco"]
    losses = calc_phase_losses(i, v_bus, duty, f_pwm, comp_pwm, dead_time, p)

    p_board = losses["p_total"] * n_active
    p_motor = v_bus * i * duty * n_active
    eff = p_motor / (p_motor + p_board) * 100 if p_motor > 0 else 0

    print("=" * 70)
    print(f"  4in1 ESC Power Loss Report  -  {p['name']}")
    print(f"  AM32 6-Step Trapezoidal  |  NSG2065Q gate driver")
    print("=" * 70)
    print(f"  Battery voltage:      {v_bus:.1f} V")
    print(f"  Phase current:        {i:.1f} A")
    print(f"  Duty cycle:           {duty*100:.1f}%")
    print(f"  PWM frequency:        {f_pwm/1e3:.0f} kHz")
    print(f"  Dead time:            {dead_time*1e9:.0f} ns  (NSG2065Q HW)")
    print(f"  Comp PWM:             {'ON' if comp_pwm else 'OFF'}")
    print(f"  Gate resistor:        {p['rg']:.0f}Ω  →  tr={p['tr']*1e9:.1f}ns  tf={p['tf']*1e9:.1f}ns")
    print(f"  Rds(on):              {p['rds_on']*1e3:.1f}mΩ cold → {rds_hot*1e3:.1f}mΩ hot (×{p['rds_tempco']})")
    print(f"  Active phases:        {n_active}")
    print("-" * 70)

    print(f"\n  Per phase pair (HS + LS MOSFET + copper):")
    print(f"    HS conduction:     {losses['p_cond_hs']:7.3f} W  (I²×Rds×D)")
    if comp_pwm:
        print(f"    LS sync rect:      {losses['p_cond_ls']:7.3f} W  (I²×Rds×(1-D))")
    else:
        print(f"    Body diode:        {losses['p_body']:7.3f} W  (Vf×I×(1-D))")
    print(f"    LOW-phase FET:     {losses['p_cond_low']:7.3f} W  (I²×Rds, 100%)")
    print(f"    Switching:         {losses['p_switch']:7.3f} W")
    print(f"    Dead time:         {losses['p_dead']:7.3f} W")
    print(f"    Reverse recovery:  {losses['p_rr']:7.3f} W  (Qrr={p['qrr']*1e9:.0f}nC)")
    print(f"    Gate drive:        {losses['p_gate']:7.3f} W")
    print(f"    ────────────────────────────────────────")
    print(f"    FET subtotal:      {losses['p_fet']:7.3f} W")
    print(f"    Copper (×2):       {losses['p_copper']:7.3f} W  ({p['r_copper']*1e3:.1f}mΩ/phase)")
    print(f"    Shunt:             {losses['p_shunt']:7.3f} W")
    print(f"    ────────────────────────────────────────")
    print(f"    Phase total:       {losses['p_total']:7.3f} W")

    print(f"\n  Board totals ({n_active} phases):")
    print(f"    Heat dissipation:  {p_board:7.2f} W")
    print(f"    Motor output:      {p_motor:7.1f} W")
    print(f"    Efficiency:        {eff:7.1f}%")

    # ─── Steady-state thermal ───
    area = p["board_area"]
    c_th = board_thermal_mass(area, p["layers"], p["oz_outer"], p["oz_inner"])

    print(f"\n  Steady-state thermal ({area:.0f}mm² board, {p['layers']}L "
          f"{p['oz_outer']:.0f}oz/{p['oz_inner']}oz):")
    print(f"  {'Scenario':<28s} {'θ':>6s}  {'ΔT':>6s}  {'Tj@25°C':>7s}  {'Tj@40°C':>7s}")
    print(f"  {'-'*62}")

    for key, sc in THERMAL_SCENARIOS.items():
        theta = board_theta(area, sc["h"])
        dt = p_board * theta
        tj25 = 25 + dt
        tj40 = 40 + dt
        w = " !! EXCEED" if tj25 > 150 else " ! HOT" if tj25 > 125 else ""
        print(f"  {sc['label']:<28s} {theta:5.1f}°/W  +{dt:4.0f}°C  {tj25:6.0f}°C  {tj40:6.0f}°C{w}")

    # ─── Transient thermal ───
    print(f"\n  Transient thermal (time to Tj=150°C from 25°C ambient):")
    print(f"  Board thermal mass: {c_th:.2f} J/K")
    print(f"  {'Scenario':<28s} {'τ':>6s}  {'t to 150°C':>10s}")
    print(f"  {'-'*50}")

    for key, sc in THERMAL_SCENARIOS.items():
        theta = board_theta(area, sc["h"])
        tau = c_th * theta
        t_max = transient_time_to_tj(p_board, theta, c_th, 150, 25)
        if t_max == float('inf'):
            t_str = "never"
        elif t_max < 1:
            t_str = f"{t_max*1000:.0f} ms"
        else:
            t_str = f"{t_max:.1f} s"
        print(f"  {sc['label']:<28s} {tau:5.1f}s   {t_str:>10s}")

    # ─── MOSFET limits ───
    p_worst_fet = max(
        losses["p_cond_hs"] + losses["p_switch"] + losses["p_dead"]/2 + losses["p_rr"],
        losses["p_cond_low"] + losses["p_body"] + losses["p_dead"]/2,
    )
    print(f"\n  MOSFET: RθJC={p['rth_jc']:.2f}°C/W  Pd_max={p['pd_max']:.0f}W  Tj_max={p['tj_max']:.0f}°C")
    print(f"  Worst single FET: {p_worst_fet:.2f}W → ΔTjc={p_worst_fet*p['rth_jc']:.1f}°C above pad")
    print("=" * 70)


def sweep(profile_key: str, currents: list, v_bus: float, duty: float,
          f_pwm: float, comp_pwm: bool, dead_time: float, n_active: int):
    p = PROFILES[profile_key]
    area = p["board_area"]
    c_th = board_thermal_mass(area, p["layers"], p["oz_outer"], p["oz_inner"])
    theta_fly = board_theta(area, 100)  # strong prop wash

    print()
    print(f"  {p['name']}  @  {v_bus:.0f}V  {duty*100:.0f}%  {f_pwm/1e3:.0f}kHz  "
          f"comp_pwm={'ON' if comp_pwm else 'OFF'}")
    print(f"  Board: {area:.0f}mm²  θ_propwash={theta_fly:.1f}°/W  C_th={c_th:.2f}J/K")
    print(f"  {'I':>6s}  {'Phase':>7s}  {'Board':>7s}  {'Eff':>5s}  "
          f"{'Tj_fly':>6s}  {'t→150°C':>8s}  {'Rating':>12s}")
    print(f"  {'-'*66}")

    for current in currents:
        losses = calc_phase_losses(current, v_bus, duty, f_pwm, comp_pwm, dead_time, p)
        p_board = losses["p_total"] * n_active
        p_motor = v_bus * current * duty * n_active
        eff = p_motor / (p_motor + p_board) * 100 if p_motor > 0 else 0
        tj_fly = 25 + p_board * theta_fly
        t_max = transient_time_to_tj(p_board, theta_fly, c_th, 150, 25)

        if t_max == float('inf'):
            t_str = "∞"
            if tj_fly < 100:
                rating = "continuous"
            elif tj_fly < 125:
                rating = "continuous*"
            else:
                rating = "marginal"
        elif t_max > 10:
            t_str = f"{t_max:.0f}s"
            rating = "burst OK"
        elif t_max > 3:
            t_str = f"{t_max:.1f}s"
            rating = "burst limit"
        else:
            t_str = f"{t_max:.1f}s"
            rating = "DANGER"

        print(f"  {current:5.0f}A  {losses['p_total']:6.2f}W  {p_board:6.1f}W  "
              f"{eff:4.1f}%  {tj_fly:5.0f}°C  {t_str:>8s}  {rating:>12s}")

    print()
    print("  continuous  = Tj < 100°C steady-state in prop wash")
    print("  continuous* = Tj 100-125°C (hot but survivable)")
    print("  marginal    = Tj 125-150°C (near limit)")
    print("  burst OK    = >10s to Tj_max (typical punch-out)")
    print("  burst limit = 3-10s to Tj_max")
    print()


def compare_boards(v_bus: float, duty: float, f_pwm: float, comp_pwm: bool,
                   dead_time: float, n_active: int):
    """Side-by-side comparison of both ESC variants."""
    currents = [5, 10, 15, 20, 25, 30, 35, 40, 50]

    print()
    print("=" * 78)
    print("  BOARD COMPARISON  -  20×20 vs 30×30")
    print(f"  {v_bus:.0f}V  {duty*100:.0f}% duty  {f_pwm/1e3:.0f}kHz  "
          f"comp_pwm={'ON' if comp_pwm else 'OFF'}  {n_active} phases")
    print("=" * 78)

    for key in ["20x20", "30x30"]:
        p = PROFILES[key]
        area = p["board_area"]
        c_th = board_thermal_mass(area, p["layers"], p["oz_outer"], p["oz_inner"])
        theta_fly = board_theta(area, 100)
        rds_hot = p["rds_on"] * p["rds_tempco"]

        print(f"\n  {p['name']}")
        print(f"  Rds(on)={rds_hot*1e3:.1f}mΩ hot  Rg={p['rg']:.0f}Ω  "
              f"Qrr={p['qrr']*1e9:.0f}nC  RθJC={p['rth_jc']:.2f}°/W")
        print(f"  θ_fly={theta_fly:.1f}°/W  C_th={c_th:.2f}J/K  "
              f"R_cu={p['r_copper']*1e3:.1f}mΩ/phase")
        print(f"  {'I':>6s}  {'Board W':>7s}  {'Eff':>5s}  "
              f"{'Tj_fly':>6s}  {'t→150°C':>8s}")
        print(f"  {'-'*44}")

        for current in currents:
            losses = calc_phase_losses(current, v_bus, duty, f_pwm, comp_pwm, dead_time, p)
            p_board = losses["p_total"] * n_active
            p_motor = v_bus * current * duty * n_active
            eff = p_motor / (p_motor + p_board) * 100 if p_motor > 0 else 0
            tj_fly = 25 + p_board * theta_fly
            t_max = transient_time_to_tj(p_board, theta_fly, c_th, 150, 25)
            t_str = "∞" if t_max == float('inf') else f"{t_max:.1f}s" if t_max < 60 else f"{t_max/60:.0f}m"
            warn = " !!" if tj_fly > 150 else " !" if tj_fly > 125 else ""
            print(f"  {current:5.0f}A  {p_board:6.1f}W  {eff:4.1f}%  "
                  f"{tj_fly:5.0f}°C  {t_str:>8s}{warn}")

    print()


def compare_pcb_options(profile_key: str, i: float, v_bus: float, duty: float,
                        f_pwm: float, comp_pwm: bool, dead_time: float, n_active: int):
    """Show impact of different PCB stackups on thermal performance."""
    p = PROFILES[profile_key]

    print()
    print(f"  PCB stackup comparison for {p['name']} @ {i:.0f}A {v_bus:.0f}V {duty*100:.0f}%")
    print("=" * 78)
    print(f"  {'Option':<38s} {'R_cu':>5s} {'Board W':>7s} {'Tj_fly':>6s} "
          f"{'t→150':>6s} {'Notes'}")
    print(f"  {'-'*76}")

    for opt_key, opt in PCB_OPTIONS.items():
        r_cu = copper_resistance_scaled(p["r_copper"], p["oz_outer"], opt["oz_outer"])
        losses = calc_phase_losses(i, v_bus, duty, f_pwm, comp_pwm, dead_time, p,
                                   r_copper_override=r_cu)
        p_board = losses["p_total"] * n_active
        area = p["board_area"]
        c_th = board_thermal_mass(area, opt["layers"], opt["oz_outer"], opt["oz_inner"])
        theta_fly = board_theta(area, 100)
        tj = 25 + p_board * theta_fly
        t_max = transient_time_to_tj(p_board, theta_fly, c_th, 150, 25)
        t_str = "∞" if t_max == float('inf') else f"{t_max:.1f}s"

        print(f"  {opt['label']:<38s} {r_cu*1e3:4.1f}  {p_board:6.1f}W  "
              f"{tj:5.0f}°C  {t_str:>5s}  {opt['notes']}")

    print()


def main():
    parser = argparse.ArgumentParser(
        description="4in1 ESC power loss calculator (AM32 6-step trapezoidal)",
        formatter_class=argparse.RawDescriptionHelpFormatter,
        epilog="""\
examples:
  %(prog)s -p 20x20 -i 30 -v 16.8 -d 80
  %(prog)s -p 30x30 -i 40 -v 25.2 -d 50 --comp-pwm
  %(prog)s -p 20x20 --sweep 5,10,15,20,25,30,35,40
  %(prog)s --compare -v 16.8 -d 80
  %(prog)s --pcb-options -p 30x30 -i 30 -v 16.8 -d 80
""")
    parser.add_argument("-p", "--profile", choices=["20x20", "30x30"], default="20x20",
                        help="ESC variant (default: 20x20)")
    parser.add_argument("-i", "--current", type=float, default=30.0)
    parser.add_argument("-v", "--voltage", type=float, default=16.8)
    parser.add_argument("-d", "--duty", type=float, default=80.0)
    parser.add_argument("-f", "--pwm-freq", type=float, default=24000)
    parser.add_argument("--dead-time", type=float, default=200e-9)
    parser.add_argument("--comp-pwm", action="store_true")
    parser.add_argument("-n", "--num-active", type=int, default=4)
    parser.add_argument("--sweep", type=str, default=None)
    parser.add_argument("--compare", action="store_true",
                        help="compare 20x20 vs 30x30 side by side")
    parser.add_argument("--pcb-options", action="store_true",
                        help="compare PCB stackup options")

    args = parser.parse_args()
    duty = args.duty / 100.0

    if args.compare:
        compare_boards(args.voltage, duty, args.pwm_freq, args.comp_pwm,
                       args.dead_time, args.num_active)
    elif args.pcb_options:
        compare_pcb_options(args.profile, args.current, args.voltage, duty,
                            args.pwm_freq, args.comp_pwm, args.dead_time, args.num_active)
    elif args.sweep:
        currents = [float(x) for x in args.sweep.split(",")]
        sweep(args.profile, currents, args.voltage, duty, args.pwm_freq,
              args.comp_pwm, args.dead_time, args.num_active)
    else:
        print_full_report(args.profile, args.current, args.voltage, duty,
                          args.pwm_freq, args.comp_pwm, args.dead_time, args.num_active)


if __name__ == "__main__":
    main()

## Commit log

2026-08-04 chore: wire shared Incutec KiCad library
    Adds incutec-hw/KiCad-Library as submodule at libs/KiCad-Library, pinned
    to the feat/complete-library build. Project lib tables gain the Incutec
    sym+fp entries via ${KIPRJMOD} relative paths. Existing local libraries
    untouched (frozen, see the library repo MANIFEST).
2026-08-04 chore: bump KiCad-Library submodule pin
2026-08-05 Fix repo slug references, untrack analysis dump, parameterize flash script
    - README.md: OpenESC_20X20 to OpenESC-20x20 (repo renamed 2026-08-05)
    - Untrack hardware/schematic_analysis.json (internal analysis dump with
    machine-local paths), ignore it going forward
    - hardware/flash_openesc20.sh: replace hardcoded personal paths with
    required AM32_UNLOCKER_DIR and AM32_DIR environment variables, add
    usage comment; flashing logic unchanged
2026-08-05 feat: add 20x20-ESC-QC press-contact QC fixture project
    New KiCad project for a bench QC jig: the assembled ESC is pressed
    face-down onto this board so pogo contacts land on its exposed pads
    (power, motor phases, DShot signals). Includes project-local libs
    (ESC-QC.kicad_sym, ESC-QC.pretty with the 4in1ESC-negative footprint,
    ESC-QC.3dshapes), the board STEP export, and a README describing the
    fixture concept and contact map.
    [20x20-ESC-QC.kicad_pcb, 20x20-ESC-QC.kicad_sch, QC-20x20-PCB.step]
2026-08-05 docs: add OSHWA certification badge to README
    Certified open source hardware, OSHWA UID BE000028. Light and dark
    badge SVGs in images/, picture element switches on color scheme.
    New README text uses the renamed repo slug OpenESC-20x20.
2026-08-05 chore: commit KiCad editor saves on schematic and project files
    Format/save churn from opening hardware/4in1-mini.kicad_sch,
    hardware/ESC.kicad_sch and the project file in KiCad. No net or
    connectivity changes intended.
    [4in1-mini.kicad_sch, ESC.kicad_sch]
2026-08-05 Track Fabrication Toolkit configs, untrack vendor datasheet PDFs
    Vendor PDFs in hardware/datasheets/ stay on disk but leave git history
    going forward; COMPONENT_REVIEW.md stays tracked. Both project
    fabrication-toolkit-options.json files are now tracked, matching
    OpenESC-30x30. Gitignore reworked to the shared repo standard: drops the
    *.md catch-all in favor of explicit local-file entries.
2026-08-05 Adopt OpenDrone repo standard docs
    README restructured to the OpenESC-30x30 layout; deep design detail
    relocated to hardware/docs/DESIGN.md. Adds CONTRIBUTING.md, AGENTS.md,
    CHANGELOG.md. Fixes verified doc defects: KiCad version, AM32 link,
    mounting hole size, J1 pin list in the QC fixture README, dead
    references to untracked files.
2026-08-05 Fix style verification findings: remove em dashes from docs and scripts
    Replace em dashes with commas, colons, or hyphens in
    COMPONENT_REVIEW.md, esc_thermal.py, v_beta_hygiene_fix.py, and
    flash_openesc20.sh per repo style rules. The DOC_TAGLINE em dash in
    4in1-mini.kicad_pro is left for the separate KiCad content pass.
    [esc_thermal.py]
2026-08-06 Rewrite CONTRIBUTING for humans: file locking, render proof, sign-off
    KiCad files cannot be merged, so the doc now leads with claiming files via
    git lfs lock and issue-first discussion, the convention used by LumenPnP and
    Ultimate Hacking Keyboard. Adds .gitattributes marking design files lockable.
    Drops the internal documentation-style rule that meant nothing to contributors.
2026-08-06 Fix contradictions and duplicated information
    Contradictions, resolved against the design files:
    - GitHub repo description corrected to KiCad 10 and 6S (schematic/PCB carry
    generator_version 10.0; DOC_INPUT is "+BATT 6S", no 3S floor is documented).
    - DOC_NAME text variable now "OpenESC-20x20", matching the repo rename, so the
    old slug stops leaking into title blocks and fabrication exports.
    - 20x20-ESC-QC/README.md no longer claims project-local libraries only: 44 of
    the 45 fixture footprints come from KiCad's stock TestPoint library. Also
    records that the fixture schematic is a stub, so the one ESC-QC symbol is
    unused.
    - esc_thermal.py header and 20x20 profile name state that SP4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
    [QC-20x20-PCB.step]
2026-08-06 Local libraries are the working default again
    New parts go into this repo's local libraries. KiCad-Library becomes a mirror
    of parts we already use or stock, worth checking first because a hit means we
    have sourced it before. Promotion into it is a separate step.
2026-08-08 Fix JST 3D model in lib, add wrl, re-render board images
    Same fix as OpenESC-30x30: the JST SM08B footprint's STEP model rendered
    the housing on stilts past the board edge. Replaced with the proven VRML
    model from OpenFC-Lite at offset (-3.5, 2.17, 0), derived from the pad
    geometry and verified by render. The J1 board-instance fix is in the
    working tree mixed with uncommitted layout and schematic work and will
    be committed with it; renders reflect that current state, verified IC
    by IC on both sides.
2026-08-08 chore: point every GitHub link at OpenDrone-hw (#20)
    * Fix JST 3D model in lib, add wrl, re-render board images
    * chore: point every GitHub link at OpenDrone-hw
    The org was renamed from incutec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
2026-08-11 docs: ask contributors to raise proposals in Discord first
    CONTRIBUTING.md now points at the Discord server and asks contributors to tag
    the developers before opening an issue or starting work, so proposals get
    checked against work in progress, board locks and committed production runs.
2026-08-11 Rev 3: input TVS removed
    The 2x SMF24A-T13 are removed. Their 24 V standoff sits below the 25.2 V a full
    6S pack reaches, so they conducted rather than protected. The board stays 6S
    only and now has no input clamp; DESIGN.md updated to say so.
    ERC and DRC reviewed by the maintainer.
    [4in1-mini.kicad_pcb, 4in1-mini.kicad_sch]
2026-08-13 Standardise: AGENTS.md, trimmed README, canonical dotfiles, design rules (#22)
    Adopts the org-wide shape, matching OpenESC-30x30. Four root files,
    CONTRIBUTING is a stub pointing at OpenDrone-hw/.github.
    AGENTS.md replaces hardware/docs/DESIGN.md and the gitignored CLAUDE.md,
    written from the design files: 6 layers, KiCad 10, no TVS, DOY180N03T power
    stage, single 0.2 mOhm shunt giving 20 mV/A and 165 A full scale, 6S only.
    hardware/4in1-mini.kicad_dru replaces a single rule conditioned on a "50Ohm"
    netclass that this board does not define, so it could never fire. It now
    carries the canonical block plus the 2 oz outer copper rule, 0.16 mm on outer
    layers only. DRC reports no clearance or w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
2026-08-13 README: standardised link row, specs from the shop, status badge (#23)
    Same shape in every board repo.
    Outbound links move out of prose into one badge row: status, shop, the product's
    Discord channel, its build video, and OSHWA where the board is certified. The
    status badge links to the stage ladder in the org CONTRIBUTING rather than
    describing the stage here.
    The specification table is synced from the product page on opendrone.be, which
    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
2026-08-14 chore: bump KiCad-Library submodule pin to 8f8093b
2026-08-14 Normalise board setup to the line standard
    The canonical dru's copper-to-copper rule demanded 0.1 mm outer
    clearance against the 0.09 line standard stated in the same file,
    flooding DRC with false errors on standard-routed boards. Removed;
    the project-file floors gate this already. Rule floors set to the
    line standard where the routed board complies, verified by DRC:
    zero new violations.
2026-08-14 Drop the KiCad-Library submodule: nothing references it
    No symbol, footprint or 3D model in the design resolves through
    libs/KiCad-Library; every part is in the repo's local libraries. The
    submodule only cost --recursive clones and pin maintenance. Lib-table
    rows for the dead Incutec nickname removed so KiCad stops warning.
2026-08-14 Rev 3.1 working state: flashing fixture, QC updates, board work
    New 20x20-ESC-Flashing pogo-pin fixture project, MotorTest project file,
    QC fixture and main board PCB updates, shop badge on the new gold.
    Internal notes and regenerable fixture STEPs stay local via the
    repo-specific .gitignore tail.
    [20x20-ESC-Flashing.kicad_pcb, 20x20-ESC-Flashing.kicad_sch, 20x20-ESC-QC.kicad_pcb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]
2026-08-14 Rev 3.1 release prep: export session state, renders, revisions
    The committed board now matches the verified fab export exactly
    (check_export.py C1-C3 clean). Renders regenerated from it.
    [4in1-mini.kicad_pcb]
2026-08-14 Correct the bulk cap numbers, measured from the board and BOM
2026-08-15 docs: standardise AGENTS.md, fix power tree topology
    AGENTS.md rebuilt on the org template, netlist-verified; current shunt corrected to series in the battery feed, flashing script and jig documented. Maintainer added to README. DOC text variables updated to 2S-6S.
2026-08-15 docs: add voltage range to input spec
    Input row now reads 2-6S LiPo (6.0-25.2 V).
2026-08-15 Move the QC fixture and flashing jig to OpenDrone-Fixtures
    20x20-ESC-QC and 20x20-ESC-Flashing now live in
    OpenDrone-hw/OpenDrone-Fixtures as OpenESC-20x20-QC and
    OpenESC-20x20-Flashing, history included. AGENTS links there.
    [20x20-ESC-Flashing.kicad_pcb, 20x20-ESC-Flashing.kicad_sch, 20x20-ESC-QC.kicad_pcb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]
2026-08-18 docs(agents): record the 470 uF supplied with every board
    The board ships with a 470 uF electrolytic for the user to solder across
    the battery terminals, the standard pairing of on-board ceramics with a
    pack-side elco. It was written down nowhere, while it dominates the bus
    capacitance once installed and therefore sets hot-plug and braking
    behaviour and the emission spectrum.
    Recorded as a supplied-not-fitted part so anything reading the parts table
    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
2026-08-22 rev3.2: CSA input network against the measured high-side feedthrough
    Same change as OpenESC-30x30 rev3.2: R91/R92 1k in the sense legs,
    C52/C54 100n 50V to ground, C51 1u across the INA186 inputs. Worst-case
    SPICE (1% R, 10% C opposed, 10 Vpp CM at 50 kHz): common-mode at the
    pins down 300x, converted differential 2.8 mVpp, DC gain error -0.08
    percent. Scale unchanged at 20 mV/A. Acceptance test: the ESC-04
    mid-throttle i_a vs clamp sweep that convicted rev3.1
    (Logs/esc-04-20x20-20260821T150430Z).
    Gates G1-G6 pass with the rev3.2 baselines; fab set 20x20_ESC_Rev3.2
    checked consistent against board and schematic. Silkscreen still reads
    rev3.1: maintainer edit pending, fab set and renders to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
    [4in1-mini.kicad_pcb, 4in1-mini.kicad_sch]
2026-08-22 3D models: retarget to KiCad stock, fix placement
    Replaces easyeda2kicad 3D models with KiCad's own where a dimension-matched
    equivalent exists. The easyeda models run 20-100x denser for the same package
    and most carry the LCEDA watermark modelled as raised geometry, which renders
    on every CAD picture of the board and is not on the real part.
    Only the (model ...) reference, offset and rotation are touched. No footprint,
    pad, land pattern, net, placement or value is modified. Applied to the footprint
    LIBRARY and the boards together: fixing only the .pretty is invisible because
    each board carries its own footprint copy, and fixing only the .kicad_pcb is
    surface level because the next placemen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
    [4in1-mini.kicad_pcb]
2026-09-02 Reorder AGENTS.md sections: design first, agent mechanics last
    New order: Architecture, (Voltage envelope,) Power, Key parts, Connectors
    and I/O, (GPIO map, Using it on a base,) Layout rules, Firmware, Repo,
    (Parts and datasheets,) Environment, Rules, Revisions.
    Claude-Session: https://claude.ai/code/session_01GiFxVPcfpNcHY5feGsgG83
2026-09-18 Align AGENTS.md with template conventions (#39)
    * Align AGENTS.md with template conventions
    * Reorder AGENTS.md sections: design first, agent mechanics last
    ---------
    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
2026-10-02 Fix JLCPCB placement for Q1-Q24, U12, J1 and the QFNs (#41) (#45)
    The Fabrication Toolkit options enabled AUTO TRANSLATE, which applies the
    toolkit's generic regex table. On this board it matched the EasyEDA-derived
    QFN-24/QFN-28 footprints (+90) and SOT-23-6 (+180), which already match the
    JLCPCB library orientation, and missed the parts that do differ.
    Compared pad 1 and pin layout of every placed footprint against the EasyEDA
    footprint of its LCSC part (easyeda2kicad):
    - Q1-Q24 (C49441966): KiCad footprint is the EasyEDA one rotated 270
    - U12 (C2058245): rotated 270
    - J1 (C160407): same rotation, origin 2.833 mm from the EasyEDA origin
    - all other placed parts: match at 0, or are two-te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
    [4in1-mini.kicad_pcb, 4in1-mini.kicad_sch, ESC.kicad_sch]
2026-11-11 chore: KiCad 10 project settings re-save (#52)
    KiCad 10 rewrites the project file on save: the zone defaults block is written out in full (KiCad defaults, min_clearance unchanged), an empty last-used STEP path is added, and the text variables are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
2026-11-11 docs(rules): kicad-skip cannot round-trip KiCad 10 schematics (#53)
    Syncs the shared Rules section from OpenDrone-hw/hardware-template (PR 16).
